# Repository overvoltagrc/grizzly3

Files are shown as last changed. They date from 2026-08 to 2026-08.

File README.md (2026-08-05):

<p align="center">
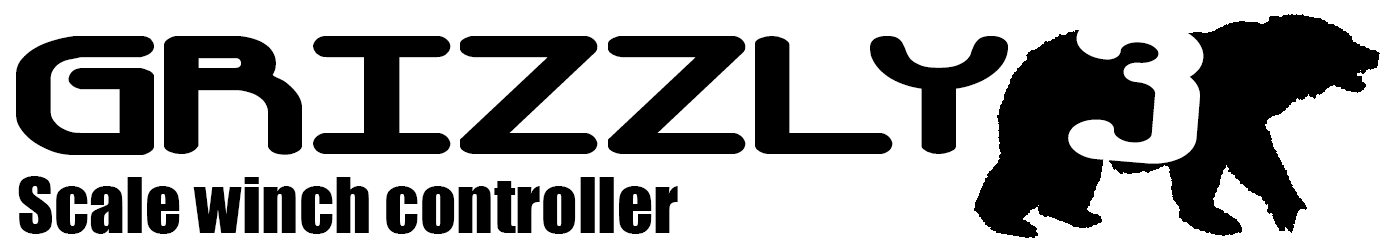
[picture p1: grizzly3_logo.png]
Grizzly3 Logo
  
</p>

# Grizzly3 — Winch Controller per verricelli R/C

Grizzly3 è una centralina elettronica per il pilotaggio di verricelli (winch) su modelli R/C (crawler, scaler, ecc.), progettata originariamente nel 2017 e ora rilasciata come progetto open source.

La scheda riceve un segnale PPM standard da un canale del ricevitore R/C e lo converte in un comando bidirezionale a PWM per pilotare il motore del verricello in avanti, indietro, con frenata attiva (drag brake) in folle.

<p align="center">
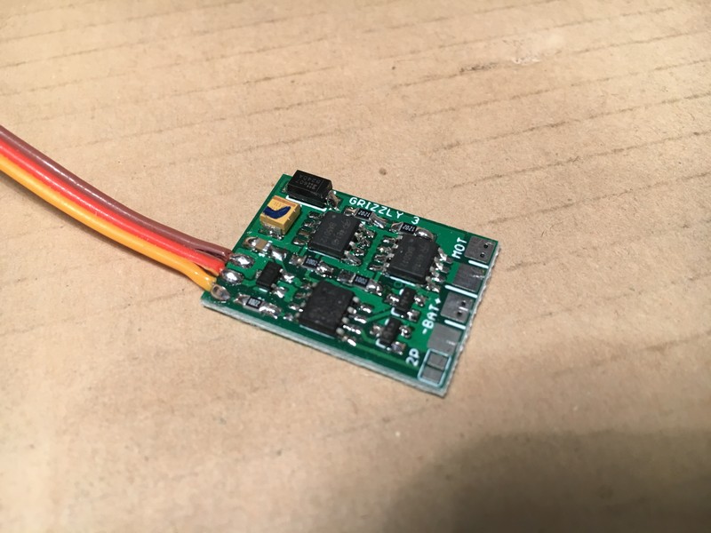
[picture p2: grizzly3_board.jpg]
Grizzly3 - Scheda assemblata
  
</p>

## 1. Il progetto

Grizzly3 è composto da tre parti:

- **Firmware** (`/fw`): codice sorgente e file `.hex` compilato per il microcontrollore PIC che gestisce la logica di lettura del comando radio e di pilotaggio del ponte a MOSFET del motore.
- **PCB** (`/brd`): file del circuito stampato disegnato in Eagle CAD, completi di file Gerber pronti per la produzione.
- **Documentazione** (`/man`, `/ref`, `/assembling`): manuale utente (IT/EN), datasheet dei componenti principali e distinta base per l'assemblaggio.

### Caratteristiche principali

- Controllo motore bidirezionale (avanti/indietro) tramite ponte H a MOSFET
- Drag brake attivo quando il comando è a riposo
- Due modalità di funzionamento selezionabili via jumper hardware:
  - **3POS**: comando proporzionale centrato (stick tipo throttle bidirezionale, es. canale motore standard)
  - **2POS**: comando a corsa singola con inversione di direzione ad ogni ripartenza dallo zero (tipico di alcuni radiocomandi con canale dedicato al verricello)
- Segnalatore acustico (buzzer) integrato
- Basato su microcontrollore PIC12F629

## 2. Funzionamento del firmware

Il firmware (`/fw/grizzly3.c`) è scritto in C per PIC a 8 bit e lavora in questo modo:

1. **Lettura del segnale PPM**: un interrupt on-change sul pin `GP3` misura, tramite Timer0, la durata dell'impulso PPM in ingresso (tipicamente 900–2100 µs).
2. **Calibrazione automatica dell'oscillatore interno**: all'avvio il firmware legge il valore di calibrazione di fabbrica memorizzato nell'ultima locazione di memoria del PIC e lo carica nel registro `OSCCAL`. Questa operazione è automatica e non richiede alcun intervento manuale.
3. **Sincronizzazione iniziale (`syncPPM`)**: alla partenza la scheda attende di ricevere un certo numero di frame PPM validi consecutivi prima di considerare il segnale radio stabile, come protezione contro segnali disturbati o glitch iniziali.
4. **Lettura del jumper JP**: in base allo stato del jumper `JP` (`GP2`), il firmware sceglie se entrare in modalità `grizzly3_3POS()` o `grizzly3_2POS()`.
5. **Generazione del PWM**: un secondo interrupt, gestito da Timer1, genera un PWM software a ~488 Hz con rampa graduale (soft-start/soft-stop) tra il valore corrente e il valore comandato, per evitare strappi meccanici sul verricello.
6. **Pilotaggio uscite**: a seconda di direzione/freno/PWM, il firmware pilota le 4 uscite verso il ponte MOSFET (`GPIO_FWD`, `GPIO_REV`, `GPIO_BRK`, `GPIO_OFF`).

## 3. Compilatore

Il firmware è scritto per essere compilato con **mikroC PRO for PIC** di [MikroElektronika](https://www.mikroe.com/mikroc-pic).

Il progetto compilato occupa circa **617 word di programma su 1024 disponibili (~60%)** sul PIC12F629, quindi rientra ampiamente nel limite di 2 KByte di codice compilato previsto dalla **licenza gratuita** di mikroC PRO for PIC. Non è quindi necessaria alcuna licenza a pagamento per compilare o modificare questo firmware.

## 4. Programmazione della scheda

**Non è necessario mettere mano al codice sorgente.** Per programmare la scheda è sufficiente:

1. Collegare il PIC12F629 montato sulla scheda (o prima del montaggio, tramite lo zoccolo/i pad ICSP) a un programmatore compatibile, ad esempio un **PICkit 2/3/4**.
2. Caricare il file **`/fw/grizzly3.hex`** già compilato, presente in questo repository.

Non sono richieste procedure di calibrazione, taratura o test iniziali successivi al flashing: la calibrazione dell'oscillatore interno è gestita automaticamente dal firmware a ogni accensione (vedi punto 2). Una volta caricato l'hex e collegata la scheda al ricevitore, la centralina è pronta all'uso — basta selezionare la modalità 2POS/3POS desiderata tramite il jumper JP prima di alimentarla.

## 5. Il PCB

Il circuito stampato è stato disegnato in **Eagle CAD** (file sorgente: `/brd/grizzly3.brd`).

Nella cartella `/brd/gerber` sono presenti tutti i file Gerber (e uno `.zip` già pronto con l'intero pacchetto) necessari per far produrre il PCB su un servizio di fabbricazione esterno, ad esempio [JLCPCB](https://jlcpcb.com/), [PCBWay](https://www.pcbway.com/) o simili: è sufficiente caricare l'archivio `.zip` (o i singoli file Gerber) nel loro configuratore online per ottenere un preventivo e ordinare le schede.

Nella cartella `/assembling` è presente la distinta componenti (`componenti.xls`) e un'immagine di riferimento per il posizionamento dei componenti SMD.

## Struttura del repository

```
grizzly3/
├── assembling/     # Distinta base (BOM) e immagine di assemblaggio
├── brd/            # Progetto Eagle CAD (.brd) e file Gerber per la produzione del PCB
├── fw/              # Sorgente firmware (mikroC) e .hex già compilato, pronto da flashare
├── man/             # Manuale utente IT/EN
├── ref/             # Datasheet dei componenti principali (PIC12F629, MOSFET, transistor)
├── grizzly3_logo.png
└── grizzly3_board.jpg  # Foto della scheda assemblata
```

## Licenza

Questo progetto è distribuito con licenza **MIT** — vedi il file [LICENSE](LICENSE).

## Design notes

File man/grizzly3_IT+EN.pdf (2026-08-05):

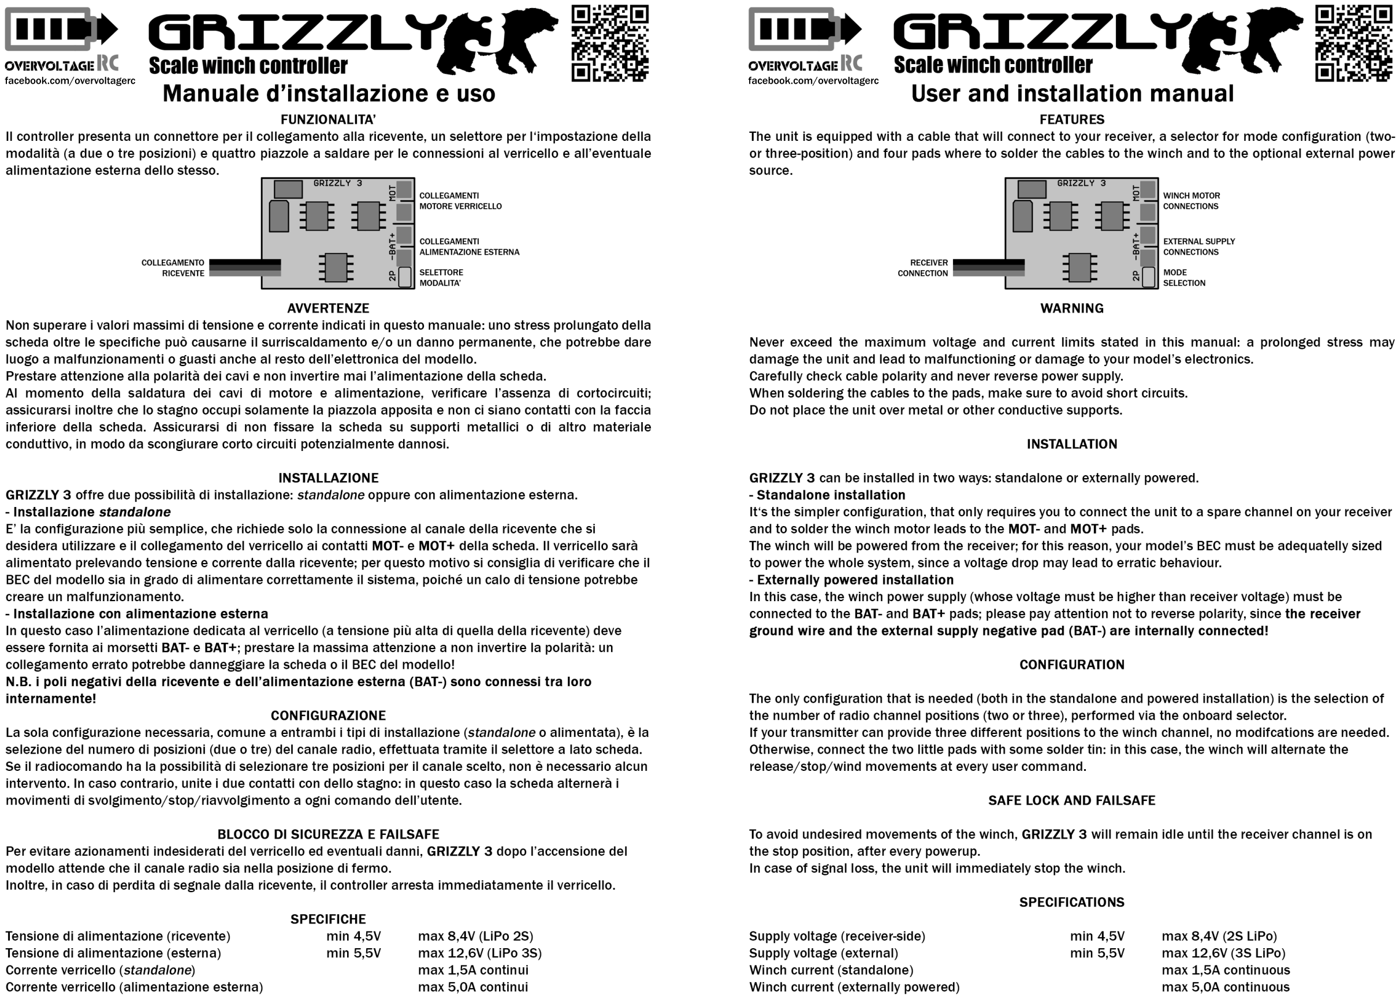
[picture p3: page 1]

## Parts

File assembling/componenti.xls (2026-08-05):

Componente | Valore | Q.tà | Codice Farnell | Note
Condensatore al tantalio SMD 3528 | 100uF 10V | 1 | 2535273
Condensatore SMD 0805 | 100nF 16V | 1 | 1759143
Diodo Schottky |  | 1 | 1843669
Regolatore SMD 4V MCP1702T-400 SOT23-3 | 4V MCP1702T-400 | 1 | 2709762
Resistenza SMD 0805 | 10 kohm | 4 |  | acquistate su eBay – Cercare alternativa su Farnell
Resistenza SMD 0805 | 2.2 kohm | 1 | 1099803
Coppia transistor MOSFET | N + P | 2 | 2061402
Transistor NPN con resistenza base interna |  | 2 | 1651085
Microcontrollore PC16F629 | PIC12F629-I/SN | 1 | 9759000

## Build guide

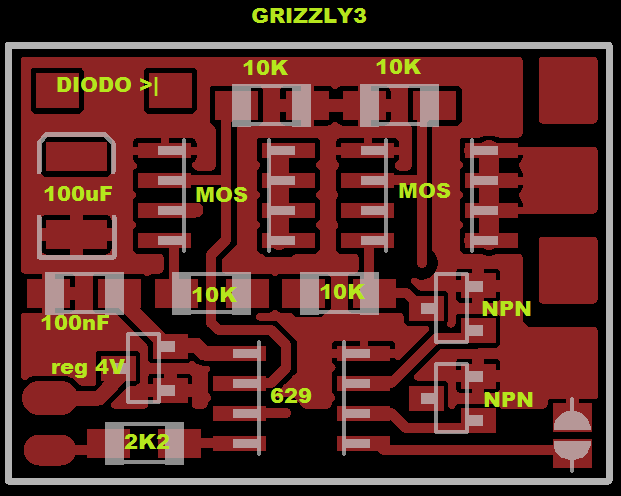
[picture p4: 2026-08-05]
assembling/grizzly3.png

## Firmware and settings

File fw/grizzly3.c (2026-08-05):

/*  Grizzly 3 Winch Controller
    2017 tHeo

    Changelog:
    29/04/17 > Porting dal firmware uESC
    
*/

#include "grizzly3.h"

// CONFIGURAZIONE PIN

sbit P2 at GP0_bit;
sbit P1 at GP1_bit;
sbit JP at GP2_bit;
sbit PPM at GP3_bit;
sbit N2 at GP4_bit;
sbit N1 at GP5_bit;

// VARIABILI
unsigned char PPM_level = 0;
unsigned char PPM_pulse = 0;
unsigned char PPM_value = 0;

unsigned char PWM_i = 0;
unsigned char PWM_semiperiod = 0;
unsigned char PWM_value = 0;
unsigned char PWM_command = 0;
unsigned char PWM_direction = PWM_IDLE;
unsigned char PWM_last_direction = PWM_REVERSE;
unsigned char PWM_brake = 0;

unsigned char i;
unsigned int j;

void interrupt()
{
    if(GPIF_bit) // Lettura comandi PPM
    {
        if(PPM && !PPM_level)
        {
            TMR0 = 0;
            PPM_level = 1;
        }
        else if(!PPM && PPM_level)
        {
            PPM_pulse = TMR0;
            PPM_level = 0;
        }

        GPIF_bit = 0;
    }

    if(T1IF_bit) // Gestione PWM
    {
        TMR1H = 255; // Precarico Timer1
        // Step PWM
        if(++PWM_i == PWM_MAX)
        {
            PWM_i = 0;

            if(PWM_value > PWM_command)
                PWM_value--;
            else if(PWM_value < PWM_command)
                PWM_value++;
        }

        if(PWM_brake)
            GPIO = GPIO_BRK;
        else if(PWM_value > PWM_i)
        {
            if(PWM_direction == PWM_FORWARD)
                GPIO = GPIO_FWD;
            else if(PWM_direction == PWM_REVERSE)
                GPIO = GPIO_REV;
        }
        else
            GPIO = GPIO_OFF;

        T1IF_bit = 0;
    }
}

void syncPPM()
{
    // Attendo segnale PPM valido
    i = 0;
    while(i < STARTUP_PPM_FRAMES)
    {
        PPM_pulse = 0;
        while(!PPM_pulse);

        if(PPM_pulse < PPM_900_US || PPM_pulse > PPM_2100_US)
            i = 0;
        else
            i++;
    }
}

void beep(unsigned int duration)
{
    for(j = 0; j < duration; j++)
    {
        P1 = 1;
        N2 = 1;

        Delay_us(500);

        N1 = 0;
        N2 = 0;
        P1 = 0;
        P2 = 0;

        Delay_us(250);

        N1 = 1;
        P2 = 1;

        Delay_us(500);

        N1 = 0;
        N2 = 0;
        P1 = 0;
        P2 = 0;

        Delay_us(250);
    }
}

void grizzly3_3POS()
{
    // Attendo che il comando sia nella posizione "verricello fermo"
    while(PPM_pulse < PPM_ZERO_LO || PPM_pulse > PPM_ZERO_HI);
    
    while(1)
    {
        // Lettura comando gas
        if(PPM_pulse > PPM_900_US)
        {
            PPM_value = PPM_pulse;
            if(PPM_value > PPM_2000_US)
                PPM_value = PPM_2000_US;
            if(PPM_value < PPM_1000_US)
                PPM_value = PPM_1000_US;

            // Elaboro segnale ricevuto
            if(PPM_value > PPM_ZERO_HI)
            {
                // AVANTI
                if(PWM_direction == PWM_FORWARD) // Sono già in avanti
                    PWM_command = PPM_map[PPM_value - PPM_1500_US]; // PWM
                else
                {
                    PWM_command = 0; // Comando 0
                    if(!PWM_value) // Motore fermo, posso invertire la rotazione
                    {
                        PWM_brake = 0;
                        PWM_direction = PWM_FORWARD;
                    }
                }
            }
            else if(PPM_value < PPM_ZERO_LO)
            {
                // INDIETRO
                if(PWM_direction == PWM_REVERSE) // Già indietro
                    PWM_command = PPM_map[PPM_1500_US - PPM_value]; // PWM
                else
                {
                    PWM_command = 0; // Comando 0
                    if(!PWM_value) // Motore fermo, posso invertire la rotazione
                    {
                        PWM_brake = 0;
                        PWM_direction = PWM_REVERSE;
                    }
                }
            }
            else
            {
                // FERMO
                if(PWM_value) // Motore ancora in movimento
                    PWM_command = 0; // Comando 0
                else
                    PWM_brake = 1; // Freno il verricello

                PWM_direction = PWM_IDLE;
            }

            PPM_pulse = 0; // Resetto valore
        }
    }
}

void grizzly3_2POS()
{
    // Attendo che il comando sia nella posizione "verricello fermo"
    while(PPM_pulse > PPM_STOP);
    
    while(1)
    {
        // Lettura comando gas
        if(PPM_pulse > PPM_900_US)
        {
            PPM_value = PPM_pulse;
            if(PPM_value > PPM_2000_US)
                PPM_value = PPM_2000_US;
            if(PPM_value < PPM_1000_US)
                PPM_value = PPM_1000_US;

            // Elaboro segnale ricevuto
            if(PPM_value > PPM_STOP)
            {
                // VERRICELLO ACCESO
                if(PWM_direction == PWM_FORWARD || pwm_direction == PWM_REVERSE) // Sono già in avanti
                    PWM_command = PPM_map[(PPM_value - PPM_1000_US) / 2]; // PWM
                else
                {
                    PWM_command = 0; // Comando 0
                    if(!PWM_value) // Motore fermo, posso invertire la rotazione
                    {
                        PWM_brake = 0;
                        if(PWM_last_direction == PWM_REVERSE)
                            PWM_direction = PWM_FORWARD;
                        else
                            PWM_direction = PWM_REVERSE;
                            
                        PWM_last_direction = PWM_direction;
                    }
                }
            }
            else
            {
                // FERMO
                if(PWM_value) // Motore ancora in movimento
                    PWM_command = 0; // Comando 0
                else
                    PWM_brake = 1; // Freno il verricello

                PWM_direction = PWM_IDLE;
            }

            PPM_pulse = 0; // Resetto valore
        }
    }
}

void main() {
    // INIZIALIZZAZIONE HARDWARE
    asm {
         bsf STATUS, RP0
         call 0x03ff
         movwf OSCCAL
         bcf STATUS, RP0
     }                          // Calibrazione oscillatore interno

    OPTION_REG = 0b00000011;    // Timer0 con prescaler 1/16 (ciclo 4,096 msec), pull-up abilitati
    WPU = 0b00000100;           // Pull-up abilitato su GP2 (JP)

    GPIO = GPIO_OFF;            // Transistor spenti
    
             //xx543210
    TRISIO = 0b11001100;        // Configuro input/output

    GIE_bit = 1;                // Interrupt abilitati
    PEIE_bit = 1;               // Interrupt periferiche abilitati
    GPIE_bit = 1;               // Interrupt-On-Change abilitato
    IOC = 0b00001000;           // IOC abilitato su GP3 (PPM)
    T1IF_bit = 0;
    T1IE_bit = 1;               // Interrupt Timer1 abilitato
    T1CON = 0b00000001;         // Timer1 con prescaler 1/1

    // Attendo segnale
    syncPPM();

    // Attivo dragbrake
    PWM_brake = 1;

    if(JP) // Lettura jumper
        grizzly3_3POS();
    else
        grizzly3_2POS();
}

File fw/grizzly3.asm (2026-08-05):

_interrupt:
	MOVWF      R15+0
	SWAPF      STATUS+0, 0
	CLRF       STATUS+0
	MOVWF      ___saveSTATUS+0
	MOVF       PCLATH+0, 0
	MOVWF      ___savePCLATH+0
	CLRF       PCLATH+0

	BTFSS      GPIF_bit+0, BitPos(GPIF_bit+0)
	GOTO       L_interrupt0
	BTFSS      GP3_bit+0, BitPos(GP3_bit+0)
	GOTO       L_interrupt3
	MOVF       _PPM_level+0, 0
	BTFSS      STATUS+0, 2
	GOTO       L_interrupt3
L__interrupt77:
	CLRF       TMR0+0
	MOVLW      1
	MOVWF      _PPM_level+0
	GOTO       L_interrupt4
L_interrupt3:
	BTFSC      GP3_bit+0, BitPos(GP3_bit+0)
	GOTO       L_interrupt7
	MOVF       _PPM_level+0, 0
	BTFSC      STATUS+0, 2
	GOTO       L_interrupt7
L__interrupt76:
	MOVF       TMR0+0, 0
	MOVWF      _PPM_pulse+0
	CLRF       _PPM_level+0
L_interrupt7:
L_interrupt4:
	BCF        GPIF_bit+0, BitPos(GPIF_bit+0)
L_interrupt0:
	BTFSS      T1IF_bit+0, BitPos(T1IF_bit+0)
	GOTO       L_interrupt8
	MOVLW      255
	MOVWF      TMR1H+0
	INCF       _PWM_i+0, 1
	MOVF       _PWM_i+0, 0
	XORLW      20
	BTFSS      STATUS+0, 2
	GOTO       L_interrupt9
	CLRF       _PWM_i+0
	MOVF       _PWM_value+0, 0
	SUBWF      _PWM_command+0, 0
	BTFSC      STATUS+0, 0
	GOTO       L_interrupt10
	DECF       _PWM_value+0, 1
	GOTO       L_interrupt11
L_interrupt10:
	MOVF       _PWM_command+0, 0
	SUBWF      _PWM_value+0, 0
	BTFSC      STATUS+0, 0
	GOTO       L_interrupt12
	INCF       _PWM_value+0, 1
L_interrupt12:
L_interrupt11:
L_interrupt9:
	MOVF       _PWM_brake+0, 0
	BTFSC      STATUS+0, 2
	GOTO       L_interrupt13
	MOVLW      48
	MOVWF      GPIO+0
	GOTO       L_interrupt14
L_interrupt13:
	MOVF       _PWM_value+0, 0
	SUBWF      _PWM_i+0, 0
	BTFSC      STATUS+0, 0
	GOTO       L_interrupt15
	MOVF       _PWM_direction+0, 0
	XORLW      0
	BTFSS      STATUS+0, 2
	GOTO       L_interrupt16
	MOVLW      33
	MOVWF      GPIO+0
	GOTO       L_interrupt17
L_interrupt16:
	MOVF       _PWM_direction+0, 0
	XORLW      1
	BTFSS      STATUS+0, 2
	GOTO       L_interrupt18
	MOVLW      18
	MOVWF      GPIO+0
L_interrupt18:
L_interrupt17:
	GOTO       L_interrupt19
L_interrupt15:
	CLRF       GPIO+0
L_interrupt19:
L_interrupt14:
	BCF        T1IF_bit+0, BitPos(T1IF_bit+0)
L_interrupt8:
L_end_interrupt:
L__interrupt82:
	MOVF       ___savePCLATH+0, 0
	MOVWF      PCLATH+0
	SWAPF      ___saveSTATUS+0, 0
	MOVWF      STATUS+0
	SWAPF      R15+0, 1
	SWAPF      R15+0, 0
	RETFIE
; end of _interrupt

_syncPPM:

	CLRF       _i+0
L_syncPPM20:
	MOVLW      50
	SUBWF      _i+0, 0
	BTFSC      STATUS+0, 0
	GOTO       L_syncPPM21
	CLRF       _PPM_pulse+0
L_syncPPM22:
	MOVF       _PPM_pulse+0, 0
	BTFSS      STATUS+0, 2
	GOTO       L_syncPPM23
	GOTO       L_syncPPM22
L_syncPPM23:
	MOVLW      56
	SUBWF      _PPM_pulse+0, 0
	BTFSS      STATUS+0, 0
	GOTO       L__syncPPM78
	MOVF       _PPM_pulse+0, 0
	SUBLW      131
	BTFSS      STATUS+0, 0
	GOTO       L__syncPPM78
	GOTO       L_syncPPM26
L__syncPPM78:
	CLRF       _i+0
	GOTO       L_syncPPM27
L_syncPPM26:
	INCF       _i+0, 1
L_syncPPM27:
	GOTO       L_syncPPM20
L_syncPPM21:
L_end_syncPPM:
	RETURN
; end of _syncPPM

_beep:

	CLRF       _j+0
	CLRF       _j+1
L_beep28:
	MOVF       FARG_beep_duration+1, 0
	SUBWF      _j+1, 0
	BTFSS      STATUS+0, 2
	GOTO       L__beep85
	MOVF       FARG_beep_duration+0, 0
	SUBWF      _j+0, 0
L__beep85:
	BTFSC      STATUS+0, 0
	GOTO       L_beep29
	BSF        GP1_bit+0, BitPos(GP1_bit+0)
	BSF        GP4_bit+0, BitPos(GP4_bit+0)
	MOVLW      166
	MOVWF      R13+0
L_beep31:
	DECFSZ     R13+0, 1
	GOTO       L_beep31
	NOP
	BCF        GP5_bit+0, BitPos(GP5_bit+0)
	BCF        GP4_bit+0, BitPos(GP4_bit+0)
	BCF        GP1_bit+0, BitPos(GP1_bit+0)
	BCF        GP0_bit+0, BitPos(GP0_bit+0)
	MOVLW      83
	MOVWF      R13+0
L_beep32:
	DECFSZ     R13+0, 1
	GOTO       L_beep32
	BSF        GP5_bit+0, BitPos(GP5_bit+0)
	BSF        GP0_bit+0, BitPos(GP0_bit+0)
	MOVLW      166
	MOVWF      R13+0
L_beep33:
	DECFSZ     R13+0, 1
	GOTO       L_beep33
	NOP
	BCF        GP5_bit+0, BitPos(GP5_bit+0)
	BCF        GP4_bit+0, BitPos(GP4_bit+0)
	BCF        GP1_bit+0, BitPos(GP1_bit+0)
	BCF        GP0_bit+0, BitPos(GP0_bit+0)
	MOVLW      83
	MOVWF      R13+0
L_beep34:
	DECFSZ     R13+0, 1
	GOTO       L_beep34
	INCF       _j+0, 1
	BTFSC      STATUS+0, 2
	INCF       _j+1, 1
	GOTO       L_beep28
L_beep29:
L_end_beep:
	RETURN
; end of _beep

_grizzly3_3POS:
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
